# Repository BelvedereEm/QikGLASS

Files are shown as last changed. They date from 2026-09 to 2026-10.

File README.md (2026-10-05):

# QikGLASS
Stained Glass Scorer using CNC 3018

A spring-loaded, self-steering glass-scoring head that drops into the spindle clamp of a **CNCTOPBAOS 3018-PRO / PRO-MAX** (GRBL, offline controller), carrying a carbide wheel head from a **QWORK 2–20 mm oil-feed glass cutter**. Swap the 775 spindle out, drop the head in, and score stained-glass patterns straight from an SVG.

**Live tool:** https://belvedereem.github.io/QikGLASS/

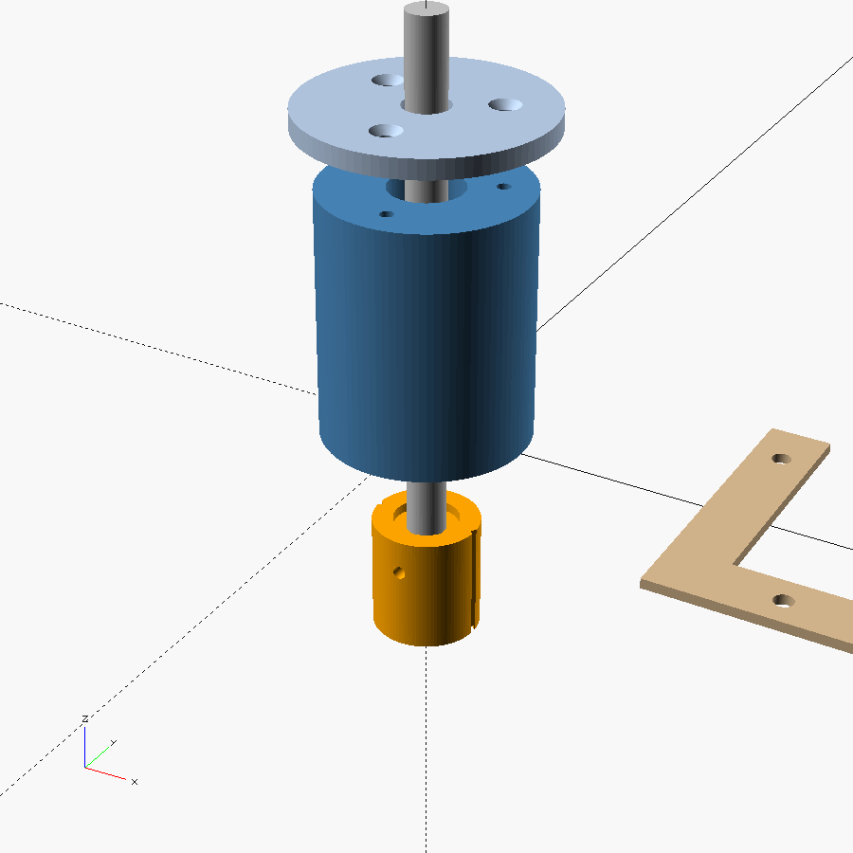
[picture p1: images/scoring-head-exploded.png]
Exploded view of the scoring head


## What's here

| Path | What it is |
|---|---|
| `index.html` | **Easy mode** (the home page): a four-step wizard. 1 Choose a picture (PNG, JPG or SVG) → 2 tap the pieces to cut → 3 pick the glass and how hard to press → 4 check the preview and save the `.nc` file, with a checklist for the machine. Set up for the swivel holder. |
| `advanced.html` | **Advanced tools**: the full Pattern → G-code page with every setting, plus the build and calibration guides. |
| `trace.html` | **PNG → SVG** (advanced): trace a picture into piece outlines and save them as an SVG. |
| `select.html` | **Select parts** (advanced): click or box-select lines in a full pattern SVG and send them to the advanced G-code page. |
| `cad/qikglass_scoring_head.scad` | Parametric OpenSCAD source for all printed parts |
| `stl/` | Every printed part at the default dimensions (listed below) |
| `images/` | Renders |

## How it works

Five printed parts plus the QWORK cutter head. No rod, bearings, metal spring, screws or clips.

- **Body** sits in the spindle clamp. A long bushing at its bottom guides the shaft.
- **Shaft** drops in from the top. Its flange stops on the body's inner lip, so nothing has to hold it in. Its **domed top** is the swivel: only the centre carries load, so it spins almost freely under 3–5 kg and the wheel steers itself. The split **collet** for the cutter is printed on its bottom end.
- **Spring** is a printed flexure (a PETG tube with staggered slots) whose solid foot sits on the dome. It supplies 2–5 kg of scoring pressure. Print it soft, medium or firm.
- **Cap** screws onto the body's printed thread and presses on the spring: turn it to adjust pressure. Each grip flute is 1/12 turn, or 0.25 mm.
- **Nut** screws up the collet and grips the QWORK head, **1.5 mm off-centre**, so the wheel trails like a caster and steers around curves. The G-code page compensates every path for that offset.

How the head goes together and attaches

## Simple holder (one part, for first tests)

`cad/qikglass_simple_holder.scad` is a one-piece holder: it drops into the 44.1 mm spindle clamp (34 mm tall), a lip rests on top of the clamp, and the QWORK head's brass thread (9.6 × 11 mm) screws into a modelled female thread in the nose. Two versions are exported, because the thread pitch isn't confirmed yet: `stl/qikglass_simple_holder_m10x1.stl` (1.0 mm pitch) and `stl/qikglass_simple_holder_3-8-24.stl` (3/8"-24, 1.058 mm pitch). Count the crests on the brass thread over 10 mm: 10 means the 1.0 version, about 9½ means the 3/8"-24 version. No spring and no swivel, so the wheel only rolls in the direction it's turned to (straight lines along X), and pressure comes straight from Z depth. Set **Caster offset 0** and **Pre-align Off** on the G-code page when using it. Measure the reach first and set `nose_len` (see the comments in the file).

Simple holder

### Swivel holder (mockup)

If the fixed wheel skids on curves, `cad/qikglass_swivel_holder.scad` is the same holder with two **608 skateboard bearings** (8 × 22 × 7 mm) inside. A printed rotor's 8 mm stem runs through both bearings, a printed C-clip holds it in, and the rotor's head carries the female 3/8"-24 thread **1.5 mm off-centre** so the wheel trails and steers itself. Draft STLs: `stl/qikglass_swivel_holder.stl`, `qikglass_swivel_rotor.stl`, `qikglass_swivel_clip.stl`. Not printed or tested yet.

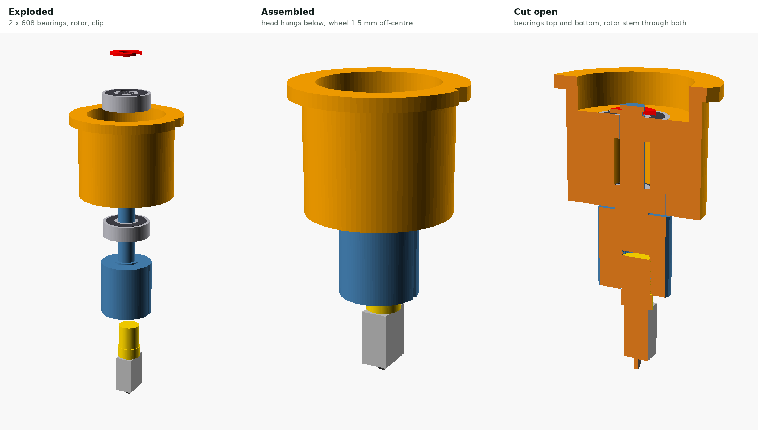
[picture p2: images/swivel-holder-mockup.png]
Swivel holder mockup


**Oil feed:** the rotor is hollow. A printed oil cup (about 1.5 ml) presses onto the top of the stem; oil runs down a 3 mm bore into a small chamber above the thread and on into the QWORK head's hollow shank, the way it fed from the original handle. The lid has a 0.8 mm vent: tape over it to slow the flow, uncover it to let oil run. Extra parts: `stl/qikglass_swivel_cup.stl`, `qikglass_swivel_lid.stl`. Set `oil = false` in the `.scad` for a solid rotor.

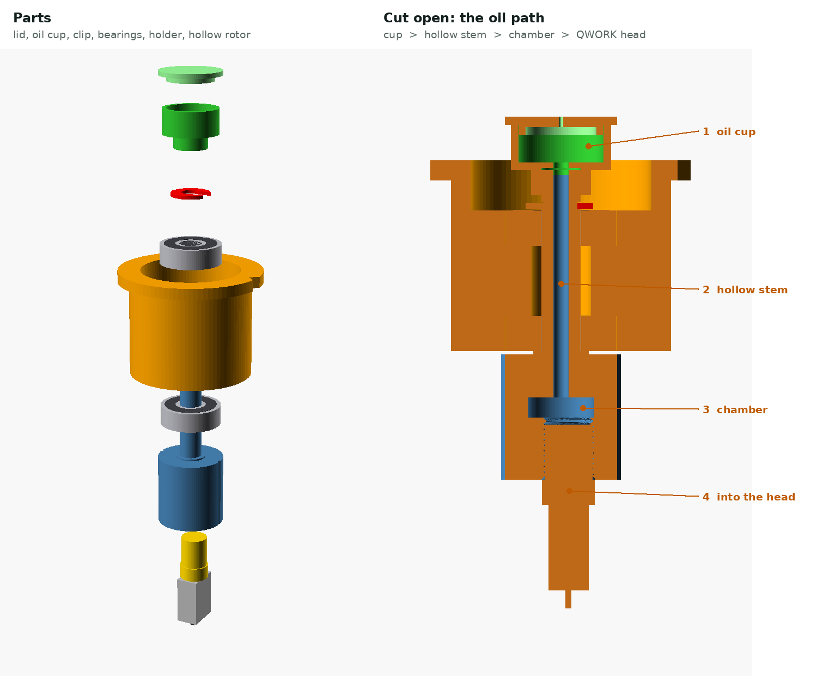
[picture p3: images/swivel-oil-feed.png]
Swivel holder oil feed


## Printed parts

| File | Notes |
|---|---|
| `qikglass_body.stl` | Upright, bushing down |
| `qikglass_shaft.stl` | Standing on its collet (already placed), 100 % infill |
| `qikglass_spring_soft/medium/firm.stl` | **PETG, 100 % infill**, foot down. ~0.5 / 0.9 / 1.6 kg per mm, max ~2 / 3.8 / 4.9 kg (estimates, check with a kitchen scale). Start with medium. |
| `qikglass_cap.stl` | Already flipped, top down |
| `qikglass_nut.stl` | Flat |
| `qikglass_pointer.stl` | Zero pointer, slides over the bottom of the shaft (cutter and nut removed) |
| `qikglass_jig.stl`, `qikglass_padstop.stl` | Glass jig and pad stop that bolt to the T-slot bed (fit a 200 mm print bed) |

PETG throughout is best (PLA creeps under constant load). 0.2 mm layers, 4 walls. Fits are tuned with `bush_clr`, `slide_clr` and `thread_clr` in the CAD file.

Also needed: the QWORK 2–6 mm cutter head, six M6 bolts with T-nuts and washers for the jig, 2 mm felt or cork, glass cutting oil, and a kitchen scale.

## Machine notes (from the kit's manual)

- Board: Woodpecker v3.4, GRBL 1.1f. Connects over a CH340 USB serial port at 115200 baud, using Candle (Grblcontrol 1.1.7) from the kit's USB stick.
- Factory speed limits: `$110`/`$111` = 1000 mm/min, `$112` = 800, acceleration 30 mm/s². The G-code page defaults to a 900 mm/min score feed and warns if you set it higher.
- The offline controller runs `.nc` files. No limit switches are fitted (`$22=0`), so zero X/Y at the jig corner with the pointer or by parking.
- The spindle clamp is a split plastic ring with one bolt. Measure its bore for `clamp_d`, and don't overtighten.

## Putting the glass in the same place every time

- **Jig:** `qikglass_jig.stl` is an L that bolts straight onto the 3018's aluminium T-slot bed with M6 bolts and T-nuts. No spoilboard is needed. The bed's slots run along X, 44 mm apart: the front rail's three bolts go in one slot (which keeps it square to X), and the left rail's two bolts drop into the next two slots back. The 6 × 4 blank goes in horizontally, pushed into the corner, and the inside corner is **X0 Y0** for every G-code file. Bolt heads sit 14 mm outside the glass, clear of the cutter. Glue 2 mm felt or cork inside the L. Rails are felt thickness + 1.5 mm tall (`felt_t`), so they stop the glass without touching the wheel. Change `slot_pitch` or `bolt_d` in the CAD file if your bed differs.
- **Pad stop:** `qikglass_padstop.stl` bolts into the front slot against the end of the rail and holds a 30 × 20 mm scrap of glass for the wheel-alignment pad, centred at X179.4 Y10 (the page's defaults).

Jig on the T-slot bed

- **Other sizes:** any rectangle can go in the jig corner. Choose **Custom size** on the G-code page and type the width (along X) and depth in inches or mm. After a job that saves a leftover strip, **Use as next blank** fills in the strip's size, and the page remembers it for next time. Width up to 160 mm, which is where the pad stop sits.
- **Squaring:** jog along the front rail with the zero pointer and tap the jig straight before screwing it down.
- **Zeroing after power-up:** the 3018 has no position memory without homing. Either take the QWORK head and nut out and slide `qikglass_pointer.stl` over the bottom of the shaft (its tip is on the swivel axis), jog it into the jig corner and zero XY, or rely on park-and-power-off: every file ends at X0 Y0, so power off there and zero XY after switching back on. With limit switches you can also enable homing and store the corner as a G54 offset.

## Packing pieces to save glass

Pieces are packed onto 6 × 4 in blanks starting at the front-left corner: left to right along the bottom, then row by row up the blank, with a gap between pieces (6 mm by default). Pieces turn 90° when that keeps the rows low. You can switch this off for glass with a grain. Anything that doesn't fit moves onto another blank, and you save one G-code file per blank.

The unused glass collects in a single strip along the back of the blank. A trim score (**T**) runs edge to edge above the top row. Break it off first and keep the strip for another project. Relief scores stop at the trim line, so the strip isn't marked.

## Relief scores

Glass won't break cleanly around a circle, a semicircle or a deep inside curve on its own. For every closed piece, the G-code page can add relief scores that run out to the edge of the 6 × 4 blank:

- **Circles and outside curves:** a pinwheel of tangent lines, each touching the curve and running to the glass edge.
- **Sharp outside corners:** the side is extended past the corner to the edge.
- **Inside curves (bites):** a comb of parallel lines out through the mouth of the curve.

Relief lines are scored after the outline and stop where they meet it, so nothing crosses. Break the relief pieces first, nearest the edge first, and then the piece. Set the density to Light, Normal or Dense.

## Quick workflow

1. Open https://belvedereem.github.io/QikGLASS/ and drop in your picture (or press **Try the example**). Type how wide the whole picture should be.
2. Tap the pieces you want. Red pieces are too big for the glass.
3. Choose the glass (6 × 4 in, the leftover strip from last time, or another size) and the score depth from glass test A.
4. Check the preview and press **Save**. Put the `.nc` file on the SD card, zero X/Y at the jig corner and Z on the glass, oil the cup, and run it. Break the green leftover line first, then the purple relief cuts, then your pieces.

Full build, calibration and safety notes are in the page's **Build the head** and **Calibrate & score** tabs.

> ⚠️ Never run a milling file with the glass head fitted, and keep glass files in their own folder on the SD card. The generated files include `M5` and never start the spindle.

## Status

Design stage. The G-code tool has been tested in a browser. The all-printed head has been checked in CAD for fit and collisions, but not printed or run on a machine yet. Spring forces are estimates, so expect to tune fits, the spring and the pressure.

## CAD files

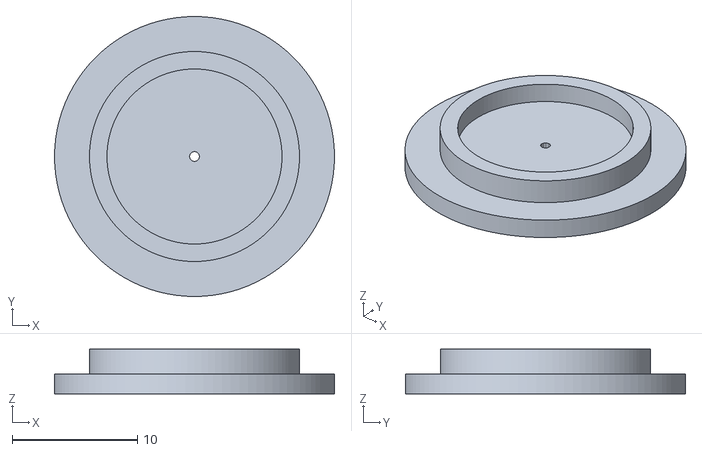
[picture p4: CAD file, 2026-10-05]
stl/qikglass_swivel_lid.stl
22.4 x 22.4 x 3.60

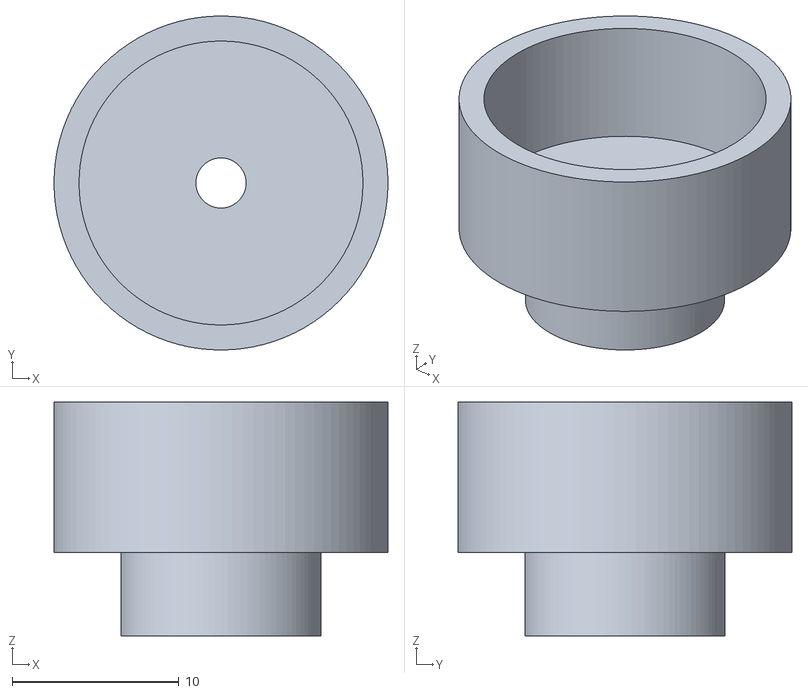
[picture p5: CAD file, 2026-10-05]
stl/qikglass_swivel_cup.stl
20.0 x 20.0 x 14.0

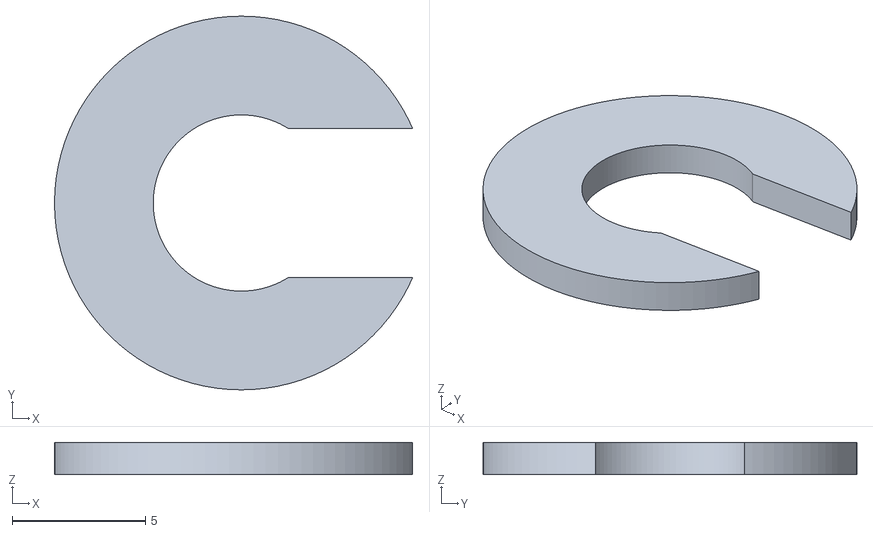
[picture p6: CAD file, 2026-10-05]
stl/qikglass_swivel_clip.stl
13.4 x 14.0 x 1.20

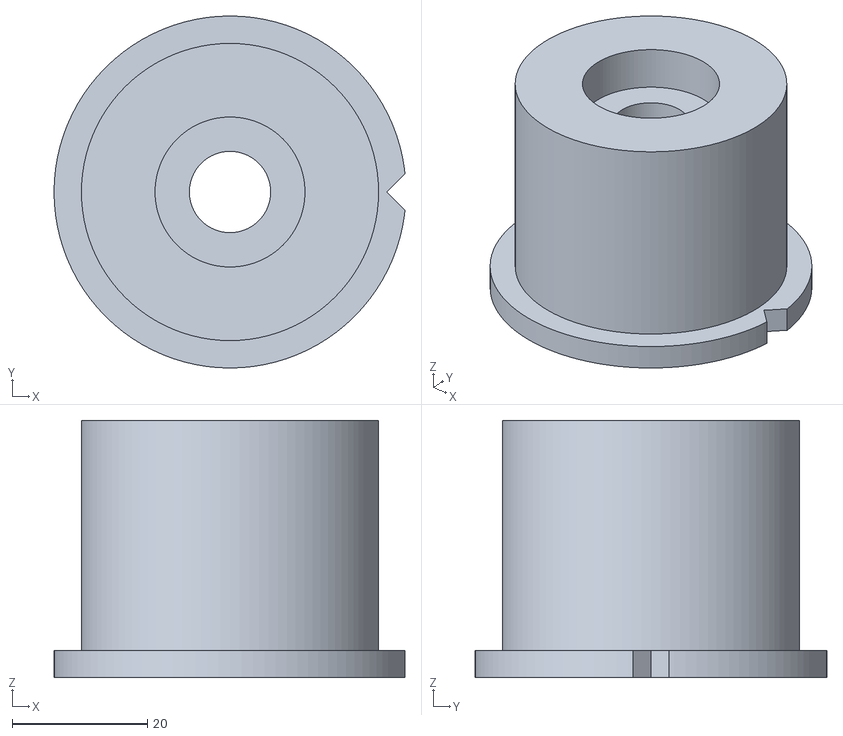
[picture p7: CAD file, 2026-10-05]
stl/qikglass_swivel_holder.stl
51.8 x 52.0 x 38.0

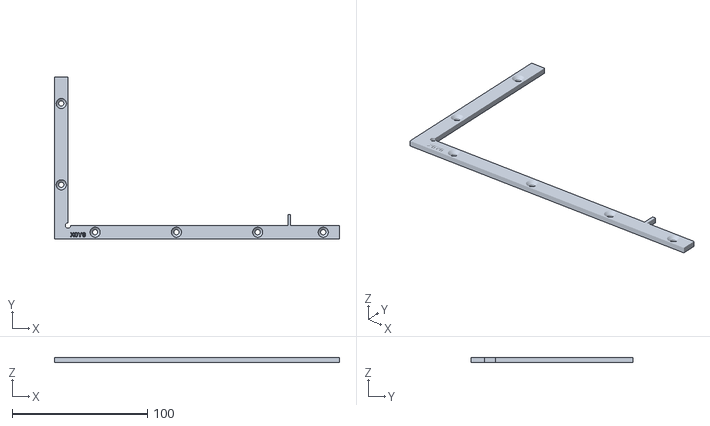
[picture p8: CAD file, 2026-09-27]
stl/qikglass_jig.stl
210.4 x 119.6 x 3.50

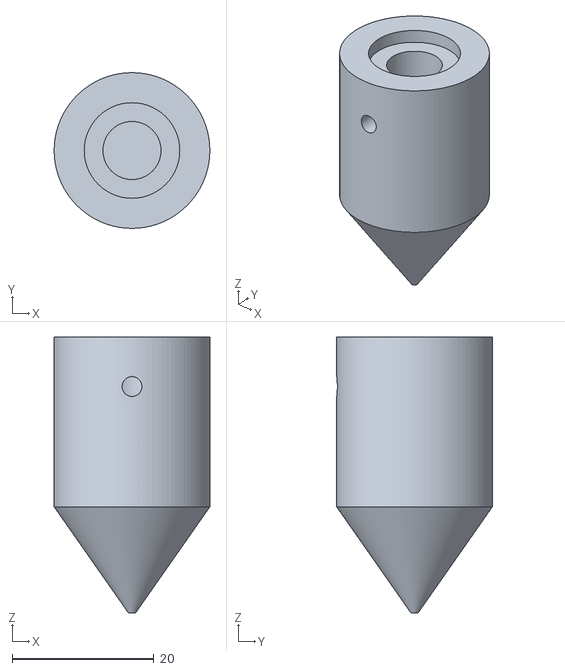
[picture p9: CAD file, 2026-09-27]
stl/qikglass_pointer.stl
22.0 x 22.0 x 39.0

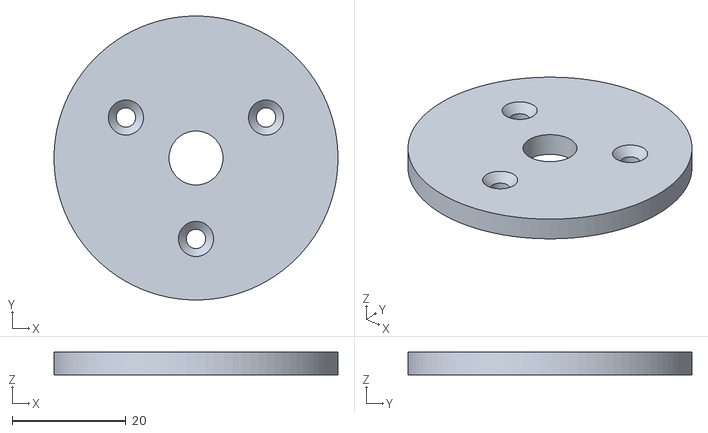
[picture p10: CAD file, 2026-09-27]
stl/qikglass_cap.stl
50.0 x 50.0 x 4.00

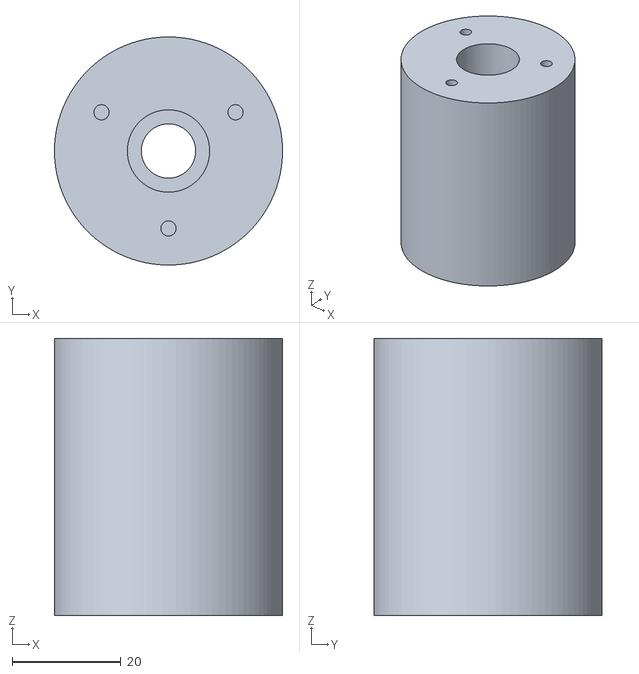
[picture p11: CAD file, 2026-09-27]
stl/qikglass_body.stl
42.0 x 42.0 x 51.0

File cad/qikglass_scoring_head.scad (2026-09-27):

// QikGLASS - spring-loaded swivel glass-scoring head for a 3018-PRO CNC
// Drops into the spindle clamp in place of the 775 spindle.
//
// How it works
//   BODY   : sits in the spindle clamp, holds two LM8UU linear bearings.
//   SHAFT  : 8 mm steel rod; slides up/down AND spins freely in the LM8UU bearings.
//   SPRING : compression spring on the shaft, between BODY bottom and CARRIER top.
//            It supplies the scoring pressure (3-4 kg) so small bed/glass
//            height errors don't change the force.
//   COLLAR : 8 mm shaft collar above the CAP stops the shaft from dropping out
//            and sets spring preload.
//   CARRIER: clamps the bottom of the shaft and holds the QWORK cutter HEAD
//            (unscrewed from its handle) offset by `caster` mm, so the wheel
//            trails behind the pivot like a shopping-cart caster and steers
//            itself around curves.
//
// Set the MEASURE-THESE values with calipers, choose `part`, press F6, export STL.

/* [Measure these first] */
// Diameter of the 775 spindle where the clamp grips it (clamp bore)
clamp_d = 42.0;
// Diameter of the cutter-head shank that screws into the handle
head_shank_d = 7.0;
// How far the head shank goes into the carrier
head_insert = 10;

/* [Scoring geometry] */
// Offset between pivot axis and wheel (caster / trail). 0 = no self-steering
caster = 1.5;

/* [Hardware] */
lm_d = 15.0;     // LM8UU outer diameter
lm_l = 24.0;     // LM8UU length
lm_fit = 0.15;   // extra bore clearance for a snug press fit (tune for your printer)
shaft_d = 8.0;
spring_od = 12.5; // spring outer diameter (inner diameter must be > 8.5)
m3_tap = 2.8;     // pilot hole for M3 screws self-tapping into plastic
m3_clear = 3.4;

/* [Glass corner fence] */
fence_h = 2.0;    // keep BELOW your glass thickness
fence_arm = 60;
fence_w = 12;

/* [6x4 glass jig] */
glass_w = 152.4;  // 6 in, always laid horizontally (along X)
glass_h = 101.6;  // 4 in
felt_t = 2.0;     // thickness of the felt/cork the glass sits on
jig_rail = 10;    // rail width
pad_w = 30;       // scrap glass for the wheel-alignment pad
pad_h = 20;
// jig rail height: above the felt, below the top of 3 mm glass
jig_h = felt_t + 1.5;

/* [Zero pointer] */
pointer_len = 39; // carrier height + how far the cutter head sticks out below it

/* [Output] */
part = "all"; // [all, body, cap, carrier, fence, jig, pointer]

$fn = 96;
eps = 0.01;

lip = 3;                       // bottom lip that the bearings sit on
body_h = 2 * lm_l + lip;       // 51 mm
cap_d = clamp_d + 8;
cap_h = 4;
screw_r = (lm_d / 2 + clamp_d / 2) / 2;

carrier_d = 22;
carrier_h = 24;
shaft_depth = 12;

module body() {
    difference() {
        cylinder(d = clamp_d, h = body_h);
        // bearing bore (bearings drop in from the top)
        translate([0, 0, lip]) cylinder(d = lm_d + lm_fit, h = body_h);
        // shaft clearance through the lip
        translate([0, 0, -eps]) cylinder(d = shaft_d + 2, h = lip + 2 * eps);
        // cap screw pilot holes
        for (a = [30, 150, 270]) rotate(a) translate([screw_r, 0, body_h - 12])
            cylinder(d = m3_tap, h = 12 + eps);
    }
}

module cap() {
    difference() {
        cylinder(d = cap_d, h = cap_h);
        translate([0, 0, -eps]) cylinder(d = shaft_d + 1.5, h = cap_h + 2 * eps);
        for (a = [30, 150, 270]) rotate(a) translate([screw_r, 0, -eps]) {
            cylinder(d = m3_clear, h = cap_h + 2 * eps);
            translate([0, 0, cap_h - 1.6]) cylinder(d1 = m3_clear, d2 = 6.2, h = 1.6 + 2 * eps);
        }
    }
}

module carrier() {
    difference() {
        cylinder(d = carrier_d, h = carrier_h);
        // shaft socket (top)
        translate([0, 0, carrier_h - shaft_depth]) cylinder(d = shaft_d + 0.2, h = shaft_depth + eps);
        // spring seat
        translate([0, 0, carrier_h - 2]) cylinder(d = spring_od + 1, h = 2 + eps);
        // shaft clamp screw (from -Y side)
        translate([0, 0, carrier_h - shaft_depth / 2 - 1]) rotate([90, 0, 0])
            cylinder(d = m3_tap, h = carrier_d);
        // cutter-head pocket, offset by caster along +X
        translate([caster, 0, -eps]) cylinder(d = head_shank_d + 0.4, h = head_insert + eps);
        // head clamp screw (from +Y side, perpendicular to the caster direction)
        translate([caster, 0, head_insert / 2]) rotate([-90, 0, 0])
            cylinder(d = m3_tap, h = carrier_d);
        // alignment grooves at +X and -X: set the wheel's plane on this line
        for (x = [carrier_d / 2, -carrier_d / 2]) translate([x, 0, carrier_h / 2])
            rotate(45) cube([1.2, 1.2, carrier_h + 2], center = true);
        // arrow notch on the bottom face showing the wheel side
        translate([carrier_d / 2 - 1, 0, 0]) rotate(45) cube([2, 2, 1.6], center = true);
    }
}

module fence() {
    difference() {
        union() {
            cube([fence_arm, fence_w, fence_h]);
            cube([fence_w, fence_arm, fence_h]);
        }
        for (p = [[fence_arm - 10, fence_w / 2], [fence_w / 2, fence_arm - 10], [fence_w + 12, fence_w / 2]])
            translate([p[0], p[1], -eps]) cylinder(d = 3.8, h = fence_h + 2 * eps);
    }
}

// 6x4 glass jig. Origin (0,0) = the inside corner = the glass blank's front-left corner = G-code X0 Y0.
// The front rail runs on to the right and holds a scrap strip for the wheel-alignment pad.
module jig() {
    L = glass_w + 12 + pad_w + 6;          // front rail length past the corner
    stub_x = glass_w + 10;                 // 2 mm stop the pad scrap sits against
    difference() {
        union() {
            translate([-jig_rail, -jig_rail, 0]) cube([L + jig_rail, jig_rail, jig_h]);            // front rail (along X)
            translate([-jig_rail, -jig_rail, 0]) cube([jig_rail, glass_h + 8 + jig_rail, jig_h]);  // left rail (along Y)
            translate([stub_x, 0, 0]) cube([2, 8, jig_h]);                                         // pad stop
        }
        // relief in the inside corner so a chipped glass corner still seats
        translate([0, 0, -eps]) cylinder(r = 2, h = jig_h + 2 * eps, $fn = 24);
        // countersunk holes for wood screws into the spoilboard
        for (x = [20, 80, 140, L - 12]) translate([x, -jig_rail / 2, 0]) screw_hole();
        for (y = [30, 90]) translate([-jig_rail / 2, y, 0]) screw_hole();
        // engraved marks: X0 Y0 at the corner, pad centre on the front rail
        translate([1.5, -jig_rail + 1.5, jig_h - 0.6]) linear_extrude(1) text("X0Y0", size = 3.5, font = "Liberation Sans:style=Bold");
        translate([stub_x + 2 + pad_w / 2, -jig_rail / 2, jig_h - 0.6]) cube([0.8, jig_rail - 3, 1], center = true);
    }
}
module screw_hole() {
    translate([0, 0, -eps]) cylinder(d = 3.8, h = jig_h + 2 * eps);
    translate([0, 0, jig_h - 1.8]) cylinder(d1 = 3.8, d2 = 7.5, h = 1.8 + eps);
}

// Zero pointer: swap it onto the shaft in place of the carrier. Its tip is exactly on the
// pivot axis, which is the point the G-code positions, so you can touch off the jig corner.
module pointer() {
    tip_len = 15;
    difference() {
        union() {
            translate([0, 0, tip_len]) cylinder(d = carrier_d, h = pointer_len - tip_len);
            cylinder(d1 = 1, d2 = carrier_d, h = tip_len);
        }
        translate([0, 0, pointer_len - shaft_depth]) cylinder(d = shaft_d + 0.2, h = shaft_depth + eps);
        translate([0, 0, pointer_len - 2]) cylinder(d = spring_od + 1, h = 2 + eps);
        translate([0, 0, pointer_len - shaft_depth / 2 - 1]) rotate([90, 0, 0]) cylinder(d = m3_tap, h = carrier_d);
    }
}

if (part == "body") body();
else if (part == "cap") cap();
else if (part == "carrier") carrier();
else if (part == "fence") fence();
else if (part == "jig") jig();
else if (part == "pointer") pointer();
else {
    // exploded assembly preview
    color("SteelBlue") body();
    color("LightSteelBlue") translate([0, 0, body_h + 12]) cap();
    color("Silver") translate([0, 0, -45]) cylinder(d = shaft_d, h = 130);
    color("Orange") translate([0, 0, -45]) carrier();
    color("Tan") translate([60, -30, 0]) fence();
}

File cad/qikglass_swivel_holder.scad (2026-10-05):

// QikGLASS SWIVEL HOLDER (mockup) - the simple holder plus two 608 skateboard bearings.
//
//   HOLDER : same outside as the simple holder (44.1 mm clamp, 34 mm grip, lip on top).
//            Two 608 bearings sit inside it, one at the bottom and one higher up,
//            with a web between them.
//   ROTOR  : printed. Its 8 mm stem passes up through both bearings. Its head hangs below
//            the holder and carries the female 3/8"-24 thread for the QWORK head,
//            1.5 mm off-centre, so the wheel trails behind the swivel and steers itself.
//            The scoring force pushes the rotor up; a small shoulder on the head presses
//            only on the lower bearing's inner race, so the bearing carries that load.
//   CLIP   : printed C-clip that snaps into a groove at the top of the stem and stops the
//            rotor dropping out when the head is lifted.
//   OIL    : the rotor is hollow. An oil cup presses onto the top of the stem; oil runs down
//            the stem's bore into a small chamber above the thread and on into the QWORK head's
//            hollow shank, the same way it fed from the original handle. The cup's lid has a
//            tiny vent: cover it with tape to slow the flow (vacuum), uncover it to let oil run.
//
// Bought parts: 2 x 608 bearings (8 x 22 x 7 mm, the skateboard size). Nothing else.

/* [Clamp] */
clamp_d = 44.1;
clamp_h = 34;
fit = 0.2;
lip_d = 52;
lip_h = 4;

/* [Bearings: 608] */
brg_id = 8; brg_od = 22; brg_w = 7;
brg_fit = 0.15;          // pocket is this much bigger than the bearing (press fit)
brg_gap = 14;            // distance between the two bearings (more = less wobble)

/* [Rotor] */
caster = 1.5;            // wheel offset behind the swivel axis
head_d = 24;
head_len = 25;           // how far the rotor head hangs below the holder (was nose_len)
stem_clr = 0.15;         // stem is this much under 8 mm so the bearings slide on

/* [Oil feed] */
oil = true;
oil_bore = 3;            // bore down the middle of the stem
cup_d = 20; cup_h = 9;   // oil cup on top of the stem (about 1.5 ml)
cup_seat = 5;            // how far the stem goes up into the cup

/* [QWORK head thread] */
thread_od = 9.6; thread_len = 11; pitch = 1.058; thread_clr = 0.35;

/* [Output] */
part = "assembled"; // [assembled, exploded, section, holder, rotor, clip, cup, lid]

$fn = 96;
eps = 0.01;
body_d = clamp_d - fit;
web = brg_gap;                                  // solid web between the bearing pockets
holder_h = clamp_h + lip_h;
stem_len = brg_w + web + brg_w + 3 + (oil ? cup_seat : 0);   // through both bearings, room for the clip (and the cup)

function thread_prof(u, rmaj, rmin) =
    let(c = 0.125, r = 0.25, f = (1 - c - r) / 2)
    u < c ? rmaj : u < c + f ? rmaj - (rmaj - rmin) * (u - c) / f :
    u < c + f + r ? rmin : rmin + (rmaj - rmin) * (u - c - f - r) / f;
module thread_cutter(d, p, h) {
    rmaj = d / 2; rmin = d / 2 - 0.5413 * p; n = 120;
    pts = [for (i = [0 : n - 1]) let(a = 360 * i / n, u = (1 - i / n) % 1)
           [thread_prof(u, rmaj, rmin) * cos(a), thread_prof(u, rmaj, rmin) * sin(a)]];
    linear_extrude(height = h, twist = -360 * h / p, slices = ceil(h / p * 48), convexity = 10) polygon(pts);
}

// HOLDER: z = 0 at its bottom face
module holder() {
    difference() {
        union() {
            cylinder(d = body_d, h = clamp_h);
            translate([0, 0, clamp_h]) cylinder(d = lip_d, h = lip_h);
        }
        // lower bearing pocket (from below) and upper pocket (from above the web)
        translate([0, 0, -eps]) cylinder(d = brg_od + brg_fit, h = brg_w + eps);
        translate([0, 0, brg_w + web]) cylinder(d = brg_od + brg_fit, h = brg_w + eps);
        // clearance for the stem through the web (only the inner races touch the stem)
        cylinder(d = 12, h = holder_h + 1);
        // lighten above the upper bearing, leaving a ledge for its outer race
        translate([0, 0, 2 * brg_w + web]) cylinder(d = body_d - 8, h = holder_h);
        // direction notch on the lip, as on the simple holder
        translate([lip_d / 2, 0, clamp_h - eps]) rotate(45) cube([4, 4, 2 * lip_h + 1], center = true);
    }
}

// ROTOR: z = 0 at the top of its head (just under the holder)
module rotor() {
    difference() {
        union() {
            translate([0, 0, -head_len]) cylinder(d = head_d, h = head_len);
            cylinder(d = 11, h = 0.6);                                 // shoulder on the inner race only
            cylinder(d = brg_id - stem_clr, h = 0.6 + stem_len);       // stem
        }
        // female thread for the QWORK head, offset by the caster
        translate([caster, 0, -head_len - eps]) thread_cutter(thread_od + thread_clr, pitch, thread_len + 1.5);
        translate([caster, 0, -head_len - eps]) cylinder(d1 = thread_od + thread_clr + 1, d2 = thread_od + thread_clr - 1.0825 * pitch, h = 1.2);
        // groove for the clip, just above the upper bearing
        translate([0, 0, 0.6 + 2 * brg_w + web + 0.3]) difference() { cylinder(d = 10, h = 1.4); cylinder(d = 6.4, h = 1.4); }
        if (oil) {
            // bore down the stem, and a chamber above the thread that feeds the head's shank
            translate([0, 0, -head_len + thread_len + 1]) cylinder(d = oil_bore, h = head_len + stem_len + 2);
            translate([0, 0, -head_len + thread_len + 1.4]) cylinder(d = 2 * (caster + thread_od / 2) + 0.6, h = 4);
        }
        // grooves showing the wheel direction (line the wheel's plane up with these)
        for (x = [head_d / 2, -head_d / 2]) translate([x, 0, -head_len / 2]) rotate(45) cube([1.2, 1.2, head_len + 2], center = true);
    }
}

module clip() {
    difference() {
        cylinder(d = 14, h = 1.2);
        translate([0, 0, -1]) cylinder(d = 6.6, h = 3);
        translate([0, -2.8, -1]) cube([10, 5.6, 3]);   // opening that snaps over the groove
    }
}

// Oil cup: presses onto the top of the stem, above the clip
module cup() {
    difference() {
        union() {
            cylinder(d = cup_d, h = cup_h);
            translate([0, 0, -cup_seat]) cylinder(d = 12, h = cup_seat + eps);   // socket that grips the stem
        }
        translate([0, 0, 1.5]) cylinder(d = cup_d - 3, h = cup_h);                // the oil well
        translate([0, 0, -cup_seat - eps]) cylinder(d = brg_id - stem_clr - 0.1, h = cup_seat + 0.5);   // press fit on the stem
        translate([0, 0, -1]) cylinder(d = oil_bore, h = 3);                       // outlet into the stem's bore
    }
}
module lid() {
    difference() {
        union() { cylinder(d = cup_d + 2.4, h = 1.6); translate([0, 0, -2]) cylinder(d = cup_d - 3.2, h = 2 + eps); }
        translate([0, 0, -3]) cylinder(d = 0.8, h = 5, $fn = 12);                  // vent: tape over it to slow the flow
        translate([0, 0, -2 - eps]) cylinder(d = cup_d - 6, h = 1.6);
    }
}

module bearing() {
    color([0.75, 0.75, 0.78]) difference() { cylinder(d = brg_od, h = brg_w); translate([0, 0, -1]) cylinder(d = brg_id, h = brg_w + 2); }
    color([0.25, 0.25, 0.28]) translate([0, 0, brg_w - 0.2]) difference() { cylinder(d = brg_od - 3, h = 0.3); cylinder(d = brg_id + 3, h = 1); }
}
module qwork() {   // stand-in for the cutter head
    color("Gold") { cylinder(d = 9.6, h = 11); translate([0, 0, -5]) cylinder(d = 10.5, h = 5); }
    color("Silver") translate([-4, -6, -22]) cube([8, 12, 17]);
    color("DimGray") translate([0, 0, -23]) rotate([0, 90, 0]) cylinder(d = 5, h = 1.2, center = true);
}

module assembly(ex = 0) {
    // shown under load: the rotor's shoulder is pressed up against the lower bearing's inner race
    r0 = -0.6;
    color("Orange") translate([0, 0, 2 * ex]) holder();
    translate([0, 0, ex * 0.6]) bearing();
    translate([0, 0, brg_w + web + ex * 3.4]) bearing();
    color("SteelBlue") translate([0, 0, r0 - ex * 0.3]) rotor();
    color("Red") translate([0, 0, r0 + 0.6 + 2 * brg_w + web + 0.3 + ex * 4.6]) clip();
    translate([caster, 0, r0 - head_len - ex * 1.6]) qwork();
    if (oil) {
        color("LimeGreen") translate([0, 0, r0 + 0.6 + stem_len + ex * 5.6]) cup();
        color("PaleGreen") translate([0, 0, r0 + 0.6 + stem_len + cup_h + ex * 6.4]) lid();
    }
}

if (part == "assembled") assembly(0);
else if (part == "exploded") assembly(14);
else if (part == "section") difference() { assembly(0); translate([-40, -80, -80]) cube([80, 80, 160]); }
else if (part == "holder") translate([0, 0, holder_h]) rotate([180, 0, 0]) holder();
else if (part == "rotor") translate([0, 0, head_len]) rotor();
else if (part == "clip") clip();
else if (part == "cup") translate([0, 0, cup_seat]) cup();
else if (part == "lid") translate([0, 0, 1.6]) rotate([180, 0, 0]) lid();
